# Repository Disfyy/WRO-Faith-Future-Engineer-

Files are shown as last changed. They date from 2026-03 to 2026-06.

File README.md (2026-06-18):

# WRO Future Engineers 2026 - Team Faith 🚀





Official repository for **Team Faith**, participating in the World Robot Olympiad (WRO) Future Engineers category. This repository contains all source code (Vision and Control), electromechanical schemes, and project documentation for our autonomous vehicle.

---

## 👋 For first-time viewers / WRO judges

If you've just landed on this repo, start here:

| What you want | Where to look |
|---|---|
| **What this robot does** | [Hardware](#-main-hardware-components-v13) and [Software Architecture](#-software-architecture) below |
| **Active firmware (the file we actually flash)** | [`src/esp32/wro_v13_main.cpp`](src/esp32/wro_v13_main.cpp) — build target 11 |
| **How we test the robot** | [Testing & Calibration Workflow](#-testing--calibration-workflow) below |
| **Source code map** | [`src/esp32/README.md`](src/esp32/README.md) (control firmware) · [`src/openmv/README.md`](src/openmv/README.md) (original vision backend) · [`src/espcam/README.md`](src/espcam/README.md) (active Pixy2 vision backend) |
| **Engineering journal** | [`docs/`](docs/) — checklists, guides, strategy, run logs, rules |
| **Engineering writeups (WRO rubric)** | [`other/`](other/) — mobility / power-and-sense / obstacle management |
| **3D-printable parts** | [`models/HSP94182_3D/`](models/HSP94182_3D/) |
| **Wiring & system diagrams** | [`schemes/`](schemes/) |
| **Photos & video** | [`v-photos/`](v-photos/), [`t-photos/`](t-photos/), [`video/`](video/) |

> 📝 The robot is in **bench calibration** as of this writing — race-day logs in [`docs/logs/`](docs/logs/) are still template-only. See [`CHANGELOG.md`](CHANGELOG.md) for status.

---

## 🏎️ Main Hardware Components (v13)
Our vehicle is built on a custom-designed reliable chassis equipped with a powerful processing stack to ensure optimal performance in both Open Challenge and Obstacle Challenge.

- **Main Controller:** ESP32-S3-DevKitC-1 N8R8 (PID, Odometry, FSM)
- **Computer Vision:** Pixy2/2.1 (active backend — color blob tracking + obstacle distance). OpenMV H7 Plus is the original/fallback backend; its OV5640 sensor failed 5 days before competition, see `wro_config_v13.h` §12.
- **IMU:** Adafruit ICM-20948 (9-DoF, on I2C0)
- **Encoders:** 2× AS5600 magnetic encoders (12-bit, dual I2C — one per bus, no mux)
- **Distance:** 2× VL53L1X ToF sensors (XSHUT-based runtime address remap)
- **Motor Driver:** BTS7960 (43A H-Bridge)
- **Steering:** JX PDI-6221MG digital servo
- **Power:** 2S/3S LiPo + 5V step-down

> **No I2C multiplexer.** The original v11 build used a TCA9548A to share one I2C bus across two AS5600s and two VL53L1Xs; that mux burned out. v13 instead uses both native I2C peripherals on the ESP32-S3 (one AS5600 per bus) and runtime XSHUT-based address remapping for the VL53L1X pair.

## 🧠 Software Architecture

Our software is divided into two continuous independent threads:
1. **Vision System (`src/openmv/`):** A MicroPython script running on the OpenMV camera. It scans for 4 target colors (Orange/Blue for directions, Red/Green for obstacles) and black walls. It calculates dynamic tracking errors and distances, transmitting payloads via UART at `115200` baud.
2. **Control System (`src/esp32/`):** A layered architecture (HAL → estimation → behavior → control → top FSM) running on the ESP32-S3. Active firmware: `wro_v13_main.cpp` (build target 11).

### Algorithms Implemented
*   **Finite State Machine (FSM):** `INIT → WAIT_START → RUN_OPEN | RUN_OBS → (corner FSM, parking FSM) → FINISH`, with `SAFE_STOP` available from any running state.
*   **Cornering FSM:** Owned by front-distance + IMU yaw delta — the camera is never an exit condition. Encoder ticks are telemetry-only during the turn.
*   **Dynamic Offset PID:** Setpoint shifts ±60 px when an active pillar is in view; far pillar provides a 0.4× pre-position term when both colors are visible.
*   **Hardware E-Stop:** Press+release arms the start; held during the race triggers `SAFE_STOP` and resumes on release.
*   **Finish Zone Odometry:** Dual AS5600 encoders track post-3-laps distance to land the robot in the finish band.
*   **Pixy2 Camera Backend:** Binary block-protocol driver (`wro_camera_pixy2.cpp`) feeding the same `g_cam` struct as the OpenMV backend, so FSM/failsafes/telemetry stay backend-agnostic. See [`docs/guides/WRO_Pixy2_Setup.md`](docs/guides/WRO_Pixy2_Setup.md).
*   **Steering Asymmetry Trim:** Live-tunable per-side steering gain compensation (`wro_steering_comp.h`) to correct chassis bias.
*   **Encoder Health Diagnostics:** Magnet-presence and connection-stability checks (target 8) run before odometry is trusted.
*   **Wi-Fi Telemetry Mirror (testing only):** Optional softAP + UDP broadcast of telemetry for bench debugging (`wro_telemetry_wifi.cpp`), gated off by default — disabled for competition per Rule 11.10.

---

## 📂 Repository Structure

```text
├── models/HSP94182_3D     # 3D chassis CAD (STL / STEP / SCAD / Python + viewer.html)
├── schemes                # Electromechanical diagrams (Mermaid + rendered PNG/SVG)
├── src
│   ├── esp32              # ESP32-S3 control firmware (C++) — v13 modular layers
│   │   ├── wro_v13_main.cpp        # Production firmware (target 11) ← active
│   │   ├── diag_*.cpp              # Diagnostic targets (2, 8, 9, 10, 12)
│   │   ├── wro_*.{cpp,h}           # Layered HAL / estimation / behavior / FSM
│   │   ├── as5600_dual_i2c.h       # AS5600 driver (dual I2C, no mux)
│   │   ├── vl53l1x_dual.h          # VL53L1X driver (XSHUT addr remap)
│   │   ├── wro_build_target.h      # Edit one line to switch target
│   │   └── legacy/                 # v11 archived sources (legacy_*.cpp + README)
│   ├── openmv              # MicroPython machine-vision scripts (original/fallback backend)
│   └── espcam              # ESP32-CAM + Pixy2 vision sketch (active backend, see espcam/README.md)
├── sketches               # Standalone Arduino sketches (bench tests, servo cal)
├── other                  # Engineering writeups by WRO topic
│   ├── mobility-management              # Drivetrain, steering, chassis, control loops
│   ├── power-and-sense-management       # Battery, power dist., sensor stack
│   └── obstacle-management              # Obstacle Challenge strategy + parking
├── docs                   # Project documentation
│   ├── INDEX.md           # Single-page navigation hub
│   ├── guides             # Wiring map, assembly, servo cal, UART protocol
│   ├── checklists         # Race-day preflight & log
│   ├── strategy           # Migration, rule compliance, audit, risk, templates
│   ├── logs               # PID / maintenance / test CSV logs
│   └── rules              # Official WRO 2026 rules (reference copies)
├── t-photos               # Team presentation photos
├── v-photos               # Vehicle engineering photos
├── video                  # Demonstration recordings
├── CHANGELOG.md           # Versioned engineering history
└── README.md              # You are here
```

## ⚙️ How to Setup

1. Assemble and wire the chassis according to [`docs/guides/WRO_Wiring_Map_v13.md`](docs/guides/WRO_Wiring_Map_v13.md).
2. Camera (active backend, Pixy2): teach signatures in PixyMon per [`docs/guides/WRO_Pixy2_Setup.md`](docs/guides/WRO_Pixy2_Setup.md) and set "Data out port" to UART @ 115200 baud. *(Fallback backend, OpenMV: connect to the IDE, run Threshold Editor to configure field lighting, and save `openmv_main.py` directly to the camera flash as `main.py`.)*
3. In Arduino IDE, install `Adafruit ICM20948`, `ESP32Servo`, and `VL53L1X` (by Pololu). Open the `src/esp32/` folder as a sketch, set `WRO_ACTIVE_TARGET` in `wro_build_target.h` to `WRO_TARGET_V13_MAIN` (target 11) and flash. Entry point is `src/esp32/wro_v13_main.cpp`.
4. Select challenge mode at compile time: `OBSTACLE_MODE 0` (Open) or `1` (Obstacle) in `src/esp32/wro_config_v13.h` (Rule 9.9: no physical mode switches). Place on the track, press the E-Stop button to start.

> ℹ️ The hardware was on a v12 plan (ESP32-S3 + AS5048A SPI + TFMini-S UART) but the new sensors didn't arrive in time and the v11 TCA9548A mux burned out. **v13 is the actual fielded build:** new ESP32-S3 main controller + original v11 sensors (AS5600 + VL53L1X), with the address conflicts resolved via dual native I2C peripherals and runtime XSHUT-based VL53L1X address remapping. See [`CHANGELOG.md`](CHANGELOG.md) and [`docs/strategy/WRO_Migration_v12_to_v13.md`](docs/strategy/WRO_Migration_v12_to_v13.md) for the full story.

---

## 🧪 Testing & Calibration Workflow

We test the robot in **two layers** before any race-pace driving:

### Layer 1 — Subsystem diagnostics

Standalone programs that verify one piece of hardware at a time. Run these in order before every test session:

| Order | What we test | How to run |
|---:|---|---|
| 1 | Both I2C buses + every address | Set target 2 ([`src/esp32/diag_scan_i2c_v13.cpp`](src/esp32/diag_scan_i2c_v13.cpp)) |
| 2 | Both AS5600 encoders: connection, magnet health, stability, odometry (keys `s`/`m`/`z`/`h`) | Set target 8 ([`src/esp32/diag_test_encoders.cpp`](src/esp32/diag_test_encoders.cpp)) |
| 3 | Both VL53L1X ToF after XSHUT remap | Set target 9 ([`src/esp32/diag_test_vl53l1x.cpp`](src/esp32/diag_test_vl53l1x.cpp)) |
| 4 | Full bench (IMU + servo + motor + camera + E-Stop) | Set target 10 ([`src/esp32/diag_bench_test_v13.cpp`](src/esp32/diag_bench_test_v13.cpp)) |
| 5 | Camera link check (active backend per `CAMERA_BACKEND`) | Set target 12 ([`src/esp32/diag_test_camera.cpp`](src/esp32/diag_test_camera.cpp)) |

Switch targets by editing one line in [`src/esp32/wro_build_target.h`](src/esp32/wro_build_target.h). Standalone `.ino` versions for the Arduino IDE live in [`sketches/`](sketches/).

### Layer 2 — Production firmware

When all 5 diagnostics pass, switch to target 11 ([`src/esp32/wro_v13_main.cpp`](src/esp32/wro_v13_main.cpp)) — the actual race firmware. It logs CSV-formatted telemetry over USB serial at 5 Hz.

### Logging

Every test-drive session is logged into [`docs/logs/`](docs/logs/):

- `WRO_Test_Log.csv` — preflight + run results (one row per session)
- `WRO_PID_Tuning_Log.csv` — controller gain experiments
- `WRO_Maintenance_Log.csv` — hardware changes

> Logs are currently **template-only** because the v13 chassis is still in bench calibration. They'll be populated as we move into floor and track testing.

### Checklists & guides

- Race-day quick check: [`docs/checklists/WRO_Quick_Race_Checklist.md`](docs/checklists/WRO_Quick_Race_Checklist.md)
- Full preflight log template: [`docs/checklists/WRO_Preflight_Log.md`](docs/checklists/WRO_Preflight_Log.md)
- Master checklist (every subsystem): [`docs/checklists/WRO_Robot_Master_Checklist_2026-03-27.md`](docs/checklists/WRO_Robot_Master_Checklist_2026-03-27.md)
- Step-by-step migration verification: [`docs/strategy/WRO_Migration_v12_to_v13.md`](docs/strategy/WRO_Migration_v12_to_v13.md)

---

## 📚 Reading Order (for judges and new readers)

1. **This README** — you are here.
2. **Engineering writeups by topic** — three short docs, one per WRO rubric area:
   - [`other/mobility-management/`](other/mobility-management/) — drivetrain, steering, chassis, control loops
   - [`other/power-and-sense-management/`](other/power-and-sense-management/) — battery, power, sensors
   - [`other/obstacle-management/`](other/obstacle-management/) — Obstacle Challenge strategy + parking
3. **Reference docs** — the [`docs/INDEX.md`](docs/INDEX.md) lists every document grouped by use-case (guides, checklists, strategy, logs, rules).
4. **Source** — vision in [`src/openmv/`](src/openmv/), control in [`src/esp32/`](src/esp32/) (entry point [`wro_v13_main.cpp`](src/esp32/wro_v13_main.cpp), tunables in [`wro_config_v13.h`](src/esp32/wro_config_v13.h)).
5. **Engineering history** — [`CHANGELOG.md`](CHANGELOG.md) tells the v11 → v12-plan → v13-actual story chronologically.

---

> *"Engineering is the closest thing to magic that exists in the world."* 
> 
> **— Team Faith**

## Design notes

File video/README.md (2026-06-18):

# `video/` — Demonstration video

Pending. The WRO Future Engineers category requires a video showing the
robot completing each challenge:

- **Open Challenge** — three full laps on the track with randomized
  inner/outer wall sections.
- **Obstacle Challenge** — three laps with red/green traffic-sign
  pillars + the magenta parking-lot finishing maneuver.

## How this will be linked

Submitted videos are typically hosted on **YouTube** (unlisted or public)
and linked from this README rather than checked into the repo — `.mp4`
files are too large for normal Git workflows.

When the first clean run is captured (per the calibration protocol, this
follows Stage 4 — first reliable 3-lap Open Challenge runs), this file
will be updated with:

- YouTube URL https://youtu.be/xa8ygO6oQPE?si=rebM9Lfaib3Sgx73
- Run date and conditions (lighting, battery voltage, firmware commit)
- Brief description of what's shown

Until then, this folder intentionally contains only a `.gitkeep`.

https://youtu.be/xa8ygO6oQPE?si=rebM9Lfaib3Sgx73

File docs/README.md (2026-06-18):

# `docs/` — WRO Future Engineers documentation

All written documentation for Team Faith's WRO robot lives here, grouped by
purpose so a judge (or a teammate) can find what they need fast.

> Looking for everything in one place? Open [`INDEX.md`](INDEX.md) for the
> full table-of-contents.

## Subfolders

| Folder | What's inside |
|---|---|
| [`guides/`](guides/) | Engineering reference: wiring map, assembly + startup, servo calibration, OpenMV UART protocol, Pixy2 setup |
| [`checklists/`](checklists/) | Race-day operations: master preflight, quick-race checklist, fillable preflight log |
| [`strategy/`](strategy/) | Analysis & planning: migration history, rule-compliance matrix, characteristics audit, track test cases, risk register, templates |
| [`logs/`](logs/) | Running CSV logs: PID tuning, maintenance, test results |
| [`rules/`](rules/) | Official WRO 2026 Future Engineers rules (reference copies, MD + PDF) |

## At a glance

### Firmware (`src/esp32/`) — for context, not maintained here

The active build is **v13** (ESP32-S3, dual native I2C, no mux). Entry point
`wro_v13_main.cpp` (target 11). v11 sources are archived under
[`../src/esp32/legacy/`](../src/esp32/legacy/).

### Recommended preflight workflow (v13)

1. `diag_scan_i2c_v13.cpp` (target 2) — verify both buses, expected addresses on each.
2. `diag_test_encoders.cpp` (target 8) — verify both AS5600s on dual-I2C: connection, magnet health, stability, then accumulate ticks.
3. `diag_test_vl53l1x.cpp` (target 9) — verify front + side VL53L1X come up post-XSHUT-remap.
4. `diag_bench_test_v13.cpp` (target 10) — full hardware sanity check.
5. `diag_test_camera.cpp` (target 12) — verify the active camera backend (Pixy2 by default, see `CAMERA_BACKEND` in `wro_config_v13.h`) responds over UART.
6. `wro_v13_main.cpp` (target 11) — wheels-up smoke test.
7. On-track tuning — straight, single corner, full lap.

For step-by-step preflight see
[`checklists/WRO_Robot_Master_Checklist_2026-03-27.md`](checklists/WRO_Robot_Master_Checklist_2026-03-27.md)
and [`checklists/WRO_Quick_Race_Checklist.md`](checklists/WRO_Quick_Race_Checklist.md).

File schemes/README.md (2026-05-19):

# Schemes

Wiring diagrams and system schematics for the WRO Future Engineers vehicle.
All files in this folder describe the **v13 hardware** (ESP32-S3 + 2× AS5600
on dual native I2C + 2× VL53L1X with XSHUT-based runtime address remap, no
TCA9548A mux).

## Files

| File | Format | Notes |
|---|---|---|
| `WRO_Wiring_Map.md` | Markdown | Summary pin table; full reference at [`../docs/guides/WRO_Wiring_Map_v13.md`](../docs/guides/WRO_Wiring_Map_v13.md) |
| `WRO_Full_System_Diagram.md` | Markdown + embedded Mermaid | System block diagram with prose |
| `WRO_Full_System_Diagram.mmd` | Mermaid source | Same diagram, source only |
| `WRO_Full_System_Diagram.svg` / `.png` | Rendered | Generated from the `.mmd` above |
| `WRO_Detailed_Wiring_Diagram.mmd` | Mermaid source | Pin-by-pin connectivity view |
| `WRO_Detailed_Wiring_Diagram.svg` / `.png` | Rendered | Generated from the `.mmd` above |

## Regenerating the rendered diagrams

If you edit a `.mmd` source, re-render with one of:

- **Mermaid CLI (mmdc):**
  ```
  npx -y @mermaid-js/mermaid-cli -i WRO_Full_System_Diagram.mmd -o WRO_Full_System_Diagram.svg
  npx -y @mermaid-js/mermaid-cli -i WRO_Full_System_Diagram.mmd -o WRO_Full_System_Diagram.png -w 2400
  npx -y @mermaid-js/mermaid-cli -i WRO_Detailed_Wiring_Diagram.mmd -o WRO_Detailed_Wiring_Diagram.svg
  npx -y @mermaid-js/mermaid-cli -i WRO_Detailed_Wiring_Diagram.mmd -o WRO_Detailed_Wiring_Diagram.png -w 2400
  ```
- **Mermaid Live Editor:** paste the `.mmd` content into [mermaid.live](https://mermaid.live/) and export.

## Authoritative pin reference

The full v13 pin map with notes lives at [`../docs/guides/WRO_Wiring_Map_v13.md`](../docs/guides/WRO_Wiring_Map_v13.md). The `.md` files in this folder summarize that reference visually.

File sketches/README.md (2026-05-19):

# `sketches/` — Standalone Arduino sketches

These are self-contained Arduino IDE sketches (one `.ino` per folder) for
**bench bring-up** and **subsystem testing**. Each one flashes to the
ESP32-S3 without the rest of the v13 codebase — useful when you want to
verify a single subsystem in isolation, or hand a tester to someone who
only has the Arduino IDE.

## How this differs from `src/esp32/`

The production firmware lives in [`../src/esp32/`](../src/esp32/) and uses a
**build-target macro system** (one sketch, switch which target compiles
via `WRO_ACTIVE_TARGET`). That's the right path for race firmware and
preflight diagnostics, but it requires opening the multi-file sketch.

The sketches in this folder are the **standalone alternative**: each is
one `.ino` with everything inlined. Open it, flash it, watch Serial.

## Sketches

| Folder | Sketch | Purpose |
|---|---|---|
| [`bench_test/`](bench_test/) | `bench_test.ino` | Full robot bench check — IMU, both AS5600, both VL53L1X (with XSHUT remap), steering servo, BTS7960 motor, E-Stop, OpenMV UART. Serial commands: `s` status, `live` toggle, `sl/sc/sr` servo, `f/b/fast/stop` motor. **Lift wheels before flashing.** |
| [`servo_calibrate/`](servo_calibrate/) | `servo_calibrate.ino` | Sweep the JX PDI-6221MG digital servo over a microsecond range to find left/center/right values. Use this to determine the `SERVO_*_US` constants in [`../src/esp32/wro_config_v13.h`](../src/esp32/wro_config_v13.h). Procedure: [`../docs/guides/WRO_Servo_Calibration_Guide.md`](../docs/guides/WRO_Servo_Calibration_Guide.md). |
| [`test_encoders/`](test_encoders/) | `test_encoders.ino` | Print live tick counts from both AS5600 encoders on dual I2C. Spin a wheel by hand; values should change smoothly. 1 revolution ≈ 4096 ticks; 1 cm ≈ 277 ticks (47 mm wheel). |

## Required libraries

Same as the main firmware:
- `Adafruit ICM20948` (+ `Adafruit BusIO` + `Adafruit Unified Sensor`)
- `ESP32Servo`
- `VL53L1X` by **Pololu**

Board: **ESP32-S3 Dev Module**. Serial Monitor: **115200 baud**.

## When to use a sketch vs. a `src/esp32/diag_*.cpp` target

| Situation | Use |
|---|---|
| Race-day preflight, you already have the main sketch open | `src/esp32/diag_*.cpp` (set `WRO_ACTIVE_TARGET`) |
| Handing a hardware test to a teammate with only Arduino IDE | This folder |
| Calibrating servo center values | `sketches/servo_calibrate/` (the diag flow doesn't have an equivalent — yet) |
| First-time bring-up after re-soldering | Either; pick the one you already have flashed |

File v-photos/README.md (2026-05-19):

# `v-photos/` — Vehicle photos

Engineering photos of the assembled Team Faith WRO v13 robot, one per
canonical view. WRO Future Engineers documentation requires photos of the
vehicle from every side so judges can evaluate mechanical design without
seeing the robot in person.

## Photos

| File | View | What's visible |
|---|---|---|
| [`top.jpeg`](top.jpeg) | Top-down | ESP32-S3-DevKitC-1, OpenMV H7 Plus camera mount, IMU, wiring harness |
| [`bottom.jpeg`](bottom.jpeg) | Bottom | Drivetrain layout, motor + gearbox, both AS5600 encoder magnets, chassis frame |
| [`front side.jpeg`](front%20side.jpeg) | Front | Steering linkage, front VL53L1X ToF, camera field-of-view direction |
| [`left side.jpeg`](left%20side.jpeg) | Left | Side VL53L1X ToF, battery placement, cable routing |
| [`right side.jpeg`](right%20side.jpeg) | Right | Motor driver (BTS7960), power distribution, E-Stop button access |

> 📝 **Captions are provisional** — they reflect what should be visible in
> each view based on the v13 build. Update this table before submission if
> any photo shows something different, and re-take any photo where the
> labeled component isn't actually visible.

## Photo requirements (per WRO Future Engineers documentation rules)

- At least one photo from each of the 6 standard views (top, bottom,
  front, back, left, right). Currently missing: **back view**.
- Photos should be sharp, well-lit, and taken against a plain background.
- The robot should be in its competition configuration (no debug wires,
  no removed panels) when photographed for the final submission.

## See also

- 3D CAD reference: [`../models/HSP94182_3D/`](../models/HSP94182_3D/) — the
  same robot from any angle, in 3D.
- Wiring diagrams: [`../schemes/`](../schemes/) — abstracted views of the
  electronics shown in these photos.

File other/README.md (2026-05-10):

# `other/` — Engineering documentation by WRO topic

The WRO Future Engineers rubric scores three engineering areas separately.
This folder organises Team Faith's design rationale by those three areas
so a judge can read each concern in isolation. Each subfolder contains a
self-contained writeup that links out to the canonical sources of truth
(source code, schematics, detailed guides) elsewhere in the repo.

| Area | Folder |
|---|---|
| Drivetrain, steering, chassis, speed control | [`mobility-management/`](mobility-management/) |
| Battery, power distribution, sensor selection & integration | [`power-and-sense-management/`](power-and-sense-management/) |
| Obstacle Challenge strategy, pillar handling, parking | [`obstacle-management/`](obstacle-management/) |

> Authoritative documentation continues to live in `docs/` and `src/`.
> Files here are explanatory writeups *about* those sources, not copies of them.

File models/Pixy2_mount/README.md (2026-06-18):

# Pixy2 / Pixy2.1 Camera Mount — WRO FE 2026 · Team Faith

Drop-in replacement for the OpenMV H7 mount after the OpenMV sensor module was
damaged (2026-06-12). Holds a **Pixy2 / Pixy2.1** board at the front of the
electronics box, aimed forward and tilted **15° down** so the lens sees the
track + pillars ahead. Reuses the **same base footprint** and matches the
**OpenMV lens height** so `PIXY_FOCAL_PIX` in `wro_config_v13.h` barely shifts.

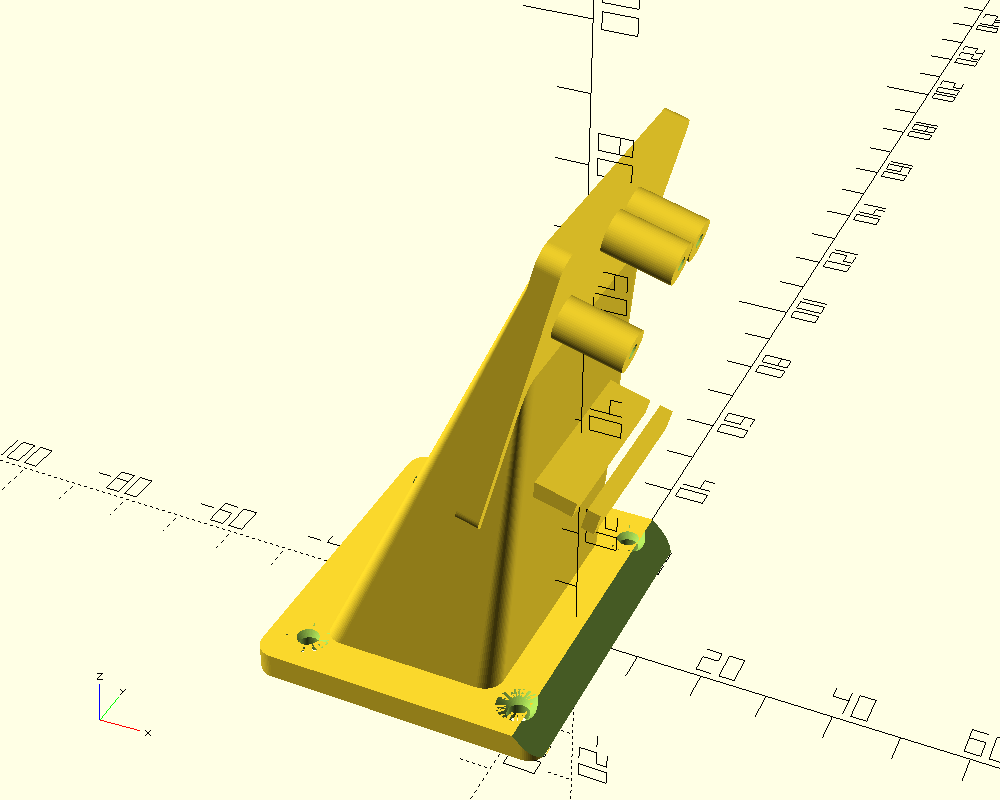
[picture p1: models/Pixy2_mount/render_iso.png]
iso

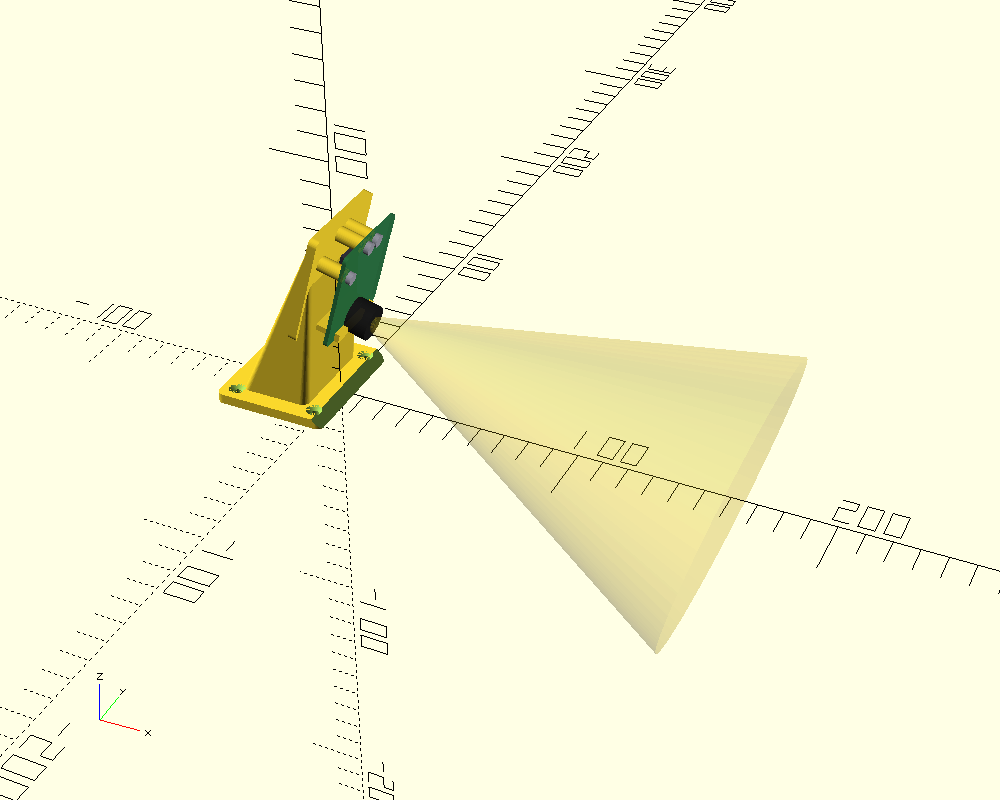
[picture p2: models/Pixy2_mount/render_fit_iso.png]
fit check

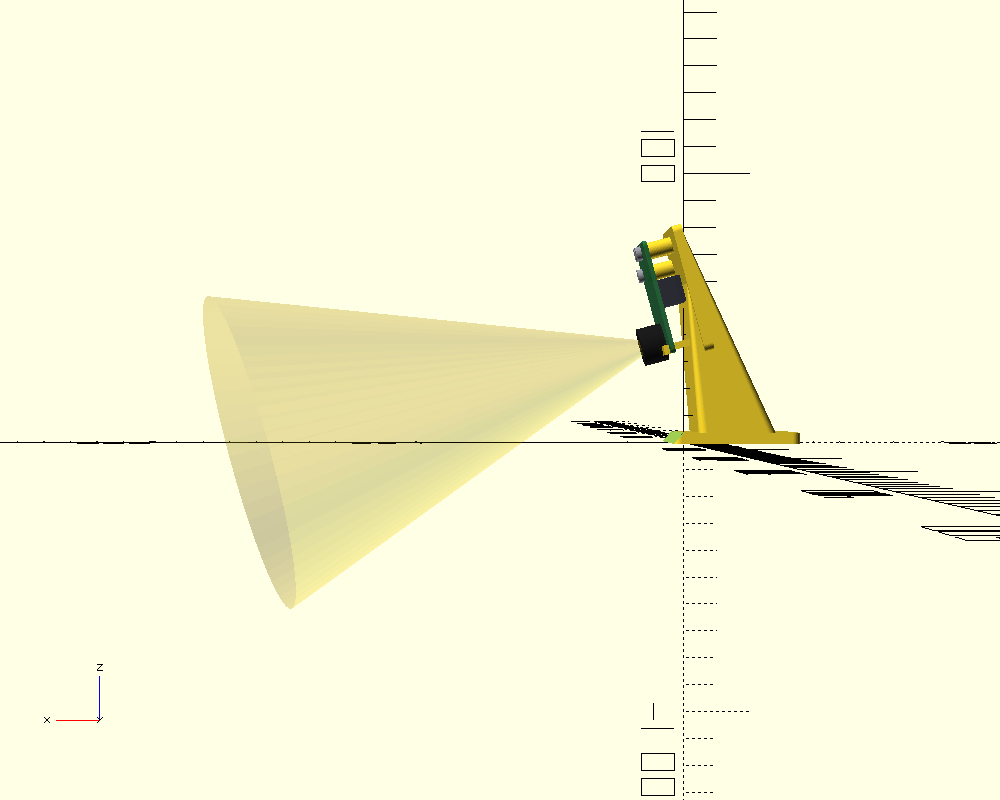
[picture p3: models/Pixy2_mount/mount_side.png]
side / aim


## Capture style — bolt-through

The board bolts onto **3 printed standoff bosses** using Pixy2's own three
mounting holes. Screws enter from the **front** (lens side); all 3 holes sit
high on the board and the lens sits low, so the heads never touch the optical
path. The 10-pin ribbon hangs in the air gap behind the board and exits a slot
in the bottom edge of the backplate. A bottom lip carries the board's weight.

## ⚠️ Correction to WRO_Pixy2_Setup.md

That guide says "M2.5, 4 holes at the corners." The
[official dimensions](https://docs.pixycam.com/wiki/doku.php?id=wiki:v2:dimensions)
say otherwise — this mount follows the official numbers:

| Spec | Official value |
|---|---|
| PCB | **38.25 × 42 mm** |
| Mounting holes | **3 holes, ⌀3.0 mm** (not 4) |
| Hole coords (corner origin) | (5.1, 31.3) · (16.0, 38.8) · (22.4, 38.8) |
| Lens centre | (19.0, 5.0) — low/centred |
| Fasteners | Pixy ships **4-40**; **M2.5** also passes the 3 mm holes |

## Hardware

- **3 × M2.5 self-tapping screws** (~6–8 mm) — board → bosses. Default pilot
  `PILOT_D = 2.1` self-taps into PLA/PETG. *(4-40 self-tappers also work.)*
- **Optional upgrade:** set `HEATSET = true` to widen the pilot for M2.5
  heat-set inserts (more re-mate cycles, better for a vibrating robot).
- **4 × M3 screws** — base → chassis (countersunk from the top, same as the
  OpenMV mount's footprint).

## Print settings

PLA or PETG · 0.2 mm layer · ≥ 30 % infill (vibration) · **supports ON** under
the backplate overhang and the bosses · brim recommended (tall, narrow part).
Print orientation: base flat on the bed (as modelled).

## Assembly

1. Bolt the base to the chassis at the **same 4 holes** the OpenMV mount used.
2. Drop the Pixy onto the 3 bosses, ribbon facing down into the rear gap.
3. Drive 3 × M2.5 from the front through the board into the bosses — snug, not
   crushing the PCB.
4. Route the ribbon down through the bottom slot to the ESP32-S3 (GPIO17/18, 5 V, GND).

## Tuning parameters (`pixy2_mount.scad`)

| Param | Default | Note |
|---|---|---|
| `TILT_DEG` | 15 | lens downtilt — keep equal to the OpenMV mount |
| `LENS_TARGET_Z` | 40 | **MEASURE your built OpenMV mount's lens height and match it** |
| `STANDOFF` | 10 | board↔backplate gap; must clear the 10-pin connector |
| `PILOT_D` / `HEATSET` | 2.1 / false | M2.5 self-tap vs heat-set insert |
| `CONN_WINDOW` | false | cut a window for the connector if you shorten `STANDOFF` |
| `CABLE_W` | 14 | ribbon slot width |

## ⚠️ Verify with calipers before printing

Same rule as the AS5600 bracket and the OpenMV mount:
- `PCB_T` (PCB thickness, ~1.6)
- the **connector block** height/footprint → confirm `STANDOFF ≥` its protrusion
- your **built OpenMV mount's lens height** → set `LENS_TARGET_Z` to match

## Note: taller than the OpenMV mount

Because Pixy's lens sits near the **bottom** of a tall board, matching the
OpenMV lens height (~40 mm) puts the board top around **77 mm**. Held by 3 top
bolts + the bottom lip it's rigid, but the centre of mass is higher than the
OpenMV mount — keep the base screws tight and re-check after a few runs.

## Export

```bash
# from this folder
openscad -o pixy2_mount.stl pixy2_mount.scad
# fit-check renders (board + lens cone + connector ghosts):
openscad -o render_fit_iso.png -D 'SHOW_GHOSTS=true' --viewall --autocenter pixy2_mount.scad
```

Set `SHOW_GHOSTS = false` (default) before exporting the printable STL.

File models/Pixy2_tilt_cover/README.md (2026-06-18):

# Pixy2 / Pixy2.1 Tilt-Adjustable Cover — WRO FE 2026 · Team Faith

A box **cover** that encloses the Pixy2 and hangs on a **clevis hinge**, so the
camera downtilt is **adjustable** (loosen one M3, swing, re-tighten) instead of
the fixed 15° of [`models/Pixy2_mount`](../Pixy2_mount/). Modelled after the
GrabCAD "Pixy Camera Case" pivot concept, fitted to Pixy2's official geometry.

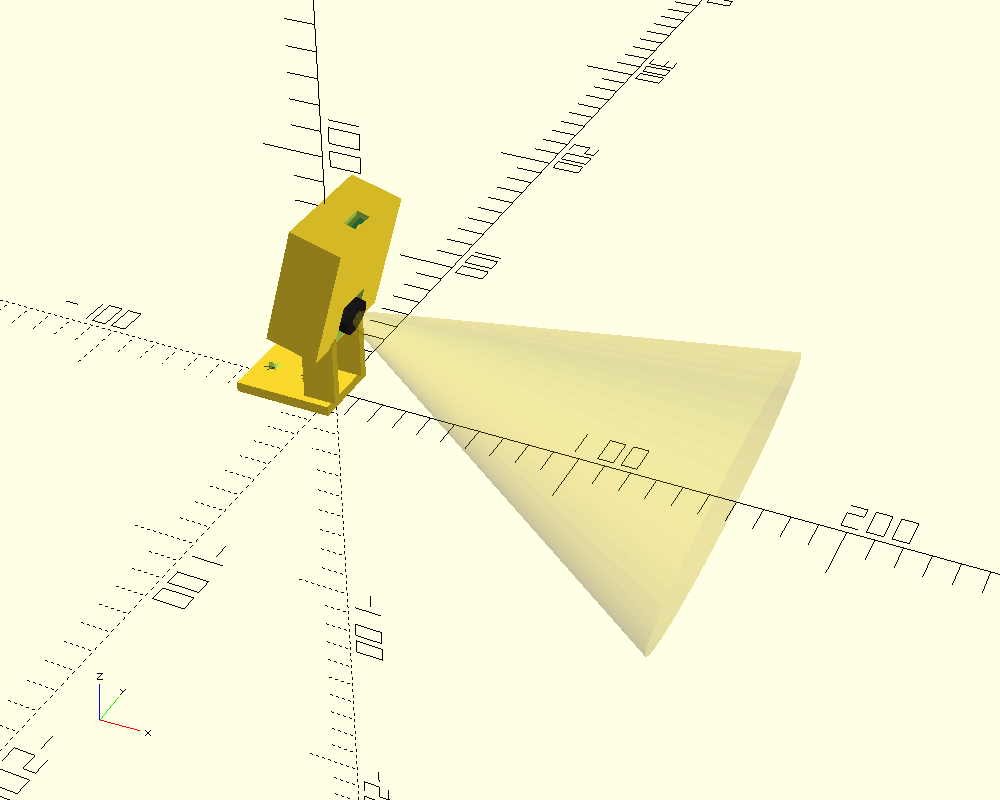
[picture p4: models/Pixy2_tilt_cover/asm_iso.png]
assembly

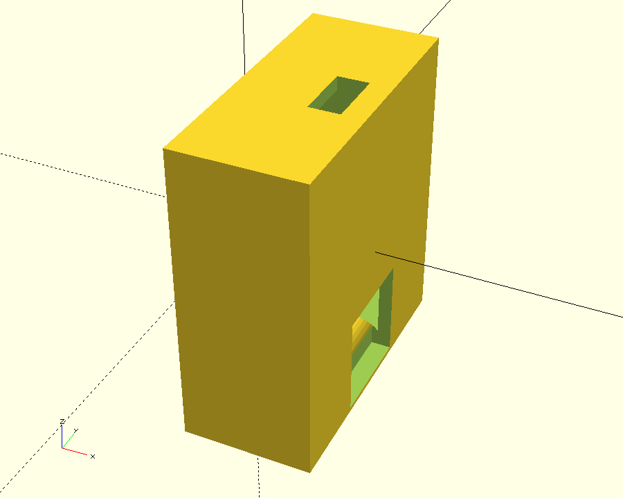
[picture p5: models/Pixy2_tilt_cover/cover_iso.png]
cover

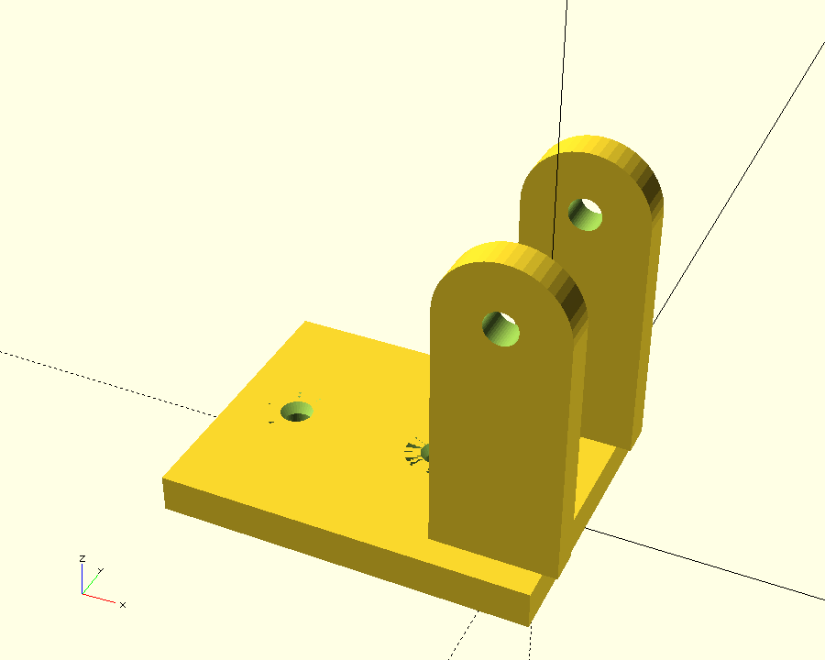
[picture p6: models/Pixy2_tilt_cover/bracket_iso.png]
bracket


## Two printed parts

| Part | File | What it is |
|---|---|---|
| **Cover** | `cover.stl` | camera box: lens window, top button slot, open back, hinge barrel |
| **Bracket** | `bracket.stl` | L-foot (chassis screws) + clevis ears that straddle the barrel |

Render each from the one source:
```bash
openscad -o cover.stl   -D 'SHOW="cover"'   pixy2_tilt_cover.scad
openscad -o bracket.stl -D 'SHOW="bracket"' pixy2_tilt_cover.scad
# assembly fit-check (board + lens cone ghost):
openscad -o asm_iso.png -D 'SHOW="assembly"' -D 'SHOW_GHOSTS=true' --viewall --autocenter pixy2_tilt_cover.scad
```

## How the tilt works

The cover's hinge **barrel** (bottom-front) sits between the bracket's two
**clevis ears**, pinned by **one M3 screw**. Loosen → the cover swings about the
horizontal pivot axis → set the downtilt → tighten to **friction-lock**.

> ⚠️ **Locking:** a single M3 on a cantilevered box can creep under vibration.
> Use an **M3 nyloc** (not a plain nut) and tighten firmly; add a **serrated /
> star washer** under the head for grip. The wide `BARREL_R = 5` gives a large
> friction radius on purpose. If it still slips, raise `BARREL_R`, or add radial
> teeth to the barrel ends + ears (future upgrade).

## Hardware

- **1 × M3 × 20 + M3 nyloc** — the pivot pin.
- **3 × M2.5 self-tapping** (~6 mm) — board → the 3 internal bosses (Pixy2's
  own 3 × ⌀3 mm holes). Insert from the **open back**.
- **2 × M3** — bracket foot → chassis (countersunk from the top).

## Assembly

1. Drop the Pixy into the cover from the **open back**, lens into the front
   window, board onto the 3 bosses; drive 3 × M2.5 from the back.
2. Route the 10-pin ribbon out the open back / bottom relief.
3. Put the barrel between the bracket ears, push the M3 through, add the nyloc
   **loosely**.
4. Bolt the bracket foot to the chassis (2 × M3).
5. Power up, watch the Pixy view, swing to the downtilt you want, **tighten the
   M3**. Re-calibrate `PIXY_FOCAL_PIX` (§4 of WRO_Pixy2_Setup.md) at the chosen
   angle.

## Print settings

PLA/PETG · 0.2 mm · ≥ 30 % infill · supports ON.
- **Cover:** print open-back-down (back opening on the bed) → walls print as
  vertical perimeters; the hinge barrel needs a little support.
- **Bracket:** print foot-down; the clevis ears need support under the rounded
  tops.

## Key parameters (`pixy2_tilt_cover.scad`)

| Param | Default | Note |
|---|---|---|
| `TILT_DEG` | 15 | **demo angle for the render only** — real tilt is set by the hinge |
| `PIVOT_Z` / `PIVOT_X` | 30 / 0 | pivot-axis height / fwd-back vs chassis |
| `BARREL_R` / `BARREL_L` | 5 / 16 | hinge barrel size (friction radius / width) |
| `PIN_D` | 3.4 | M3 pivot clearance |
| `CONN_DEPTH` / `LENS_BARREL` | 11 / 9 | **MEASURE** connector + lens protrusion |
| `PCB_T` | 1.6 | **MEASURE** |
| `WIN_HALF` | 8 | lens window half-size (clears the 14 mm barrel) |

## ⚠️ Verify with calipers before printing

- `PCB_T`, the **lens-barrel length** (`LENS_BARREL`), and the **connector
  depth** (`CONN_DEPTH`) — these set the box depth and whether the lens reaches
  the window / the connector clears the interior.
- Pixy2 board + holes follow
  [official dims](https://docs.pixycam.com/wiki/doku.php?id=wiki:v2:dimensions):
  38.25 × 42 mm, 3 × ⌀3 mm holes at (5.1,31.3)(16,38.8)(22.4,38.8), lens (19,5).

## vs. the fixed mount

| | `Pixy2_mount` (fixed) | `Pixy2_tilt_cover` (this) |
|---|---|---|
| Tilt | fixed 15° (re-print to change) | **adjustable, locked by M3** |
| Protection | open cradle | **enclosed box cover** |
| Parts / hardware | 1 part, 3×M2.5 + 4×M3 | 2 parts, +1×M3 nyloc pivot |
| Risk | none moving | pivot can creep if under-tightened |

Use the fixed mount once the best angle is known; use this to **find** that
angle on the track, or if you want the lens protected.

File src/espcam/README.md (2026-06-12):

# ESP32-CAM аварийное зрение (план Б вместо OpenMV)

**Зачем:** сенсор-модуль OpenMV H7 Plus повреждён (2026-06-12), до соревнования 5 дней.
Эта прошивка превращает ESP32-CAM в «поддельный OpenMV»: она шлёт **тот же UART-кадр
v3.1** (`RedX,RedDist,GreenX,GreenDist,ModeFlag,ExtraTag*XX\n`, 115200 8N1), поэтому
**прошивка робота (wro_v13_main.cpp) не меняется вообще**.

Файл: `espcam_vision/espcam_vision.ino`

---

## 1. Прошивка платы

Нужен USB-TTL адаптер (CH340/FTDI/CP2102) или подставка ESP32-CAM-MB.

| USB-TTL | ESP32-CAM |
|---|---|
| TX | U0R |
| RX | U0T |
| GND | GND |
| 5V | 5V |

1. Замкни **IO0 → GND** проводом.
2. Подключи USB — плата в режиме загрузки.
3. Arduino IDE: плата **"AI Thinker ESP32-CAM"** (Tools → Board → esp32).
4. Открой `espcam_vision.ino` → Upload.
5. После «Done uploading» сними перемычку IO0, нажми RST.
6. В Serial Monitor (115200) должно появиться `[CAM] OV2640 up` и `[NET] tuner at http://192.168.4.1`.

**Если плата не AI-Thinker** (нет надписи) — сфотографировать и спросить Claude,
распиновка камеры может отличаться.

## 2. Подключение к роботу

| ESP32-CAM | Куда |
|---|---|
| GPIO13 (TX) | ESP32-S3 **GPIO17** (UART2 RX — туда, где был TX OpenMV) |
| GND | GND робота |
| 5V | 5V с бака (≥500 мА). **НЕ** с пина 3V3 |

- **GPIO12 не подключать никуда** (страповый пин — плата не загрузится).
- Линия односторонняя: камера только передаёт, как и OpenMV.

## 3. Настройка порогов (вместо OpenMV IDE)

1. Подключись с ноутбука/телефона к WiFi **WRO-CAM**, пароль **wro2026fe**.
2. Открой **http://192.168.4.1** — там живая картинка, счётчики пикселей по
   каждому цвету и ползунки порогов (YCbCr: Y — яркость, Cb — «синева», Cr — «краснота»).
3. Ставь объект перед камерой → двигай ползунки, пока `px` объекта большой и
   стабильный, а на пустой сцене — ноль.
4. Камера: сначала сними галочки AEC/AGC/AWB и подбери exp/gain так, чтобы белый
   пол был белым (это аналог нашей фиксации экспозиции на OpenMV).
5. **Жми SAVE** — настройки сохраняются во флеш и переживают перезагрузку.

Порядок цветов на странице: RED, GREEN, ORANGE, BLUE, MAGENTA.

## 4. Калибровка дистанции (FOCAL)

1. Красный столбик ровно на **50 см** от объектива.
2. На странице смотри `RED ... h:<пиксели>`.
3. `focal = 50 * h / 10` → впиши в поле focal → SAVE.

## 5. Проверка связки с роботом

На ESP32-S3 в Serial Monitor должны пойти пакеты камеры (как раньше от OpenMV).
Если робот пишет camera offline — проверь: GPIO13→GPIO17, общий GND, 115200.

## 6. ⚠️ БОЕВАЯ СБОРКА (перед соревнованием)

В начале `espcam_vision.ino` поставить:

```cpp
#define ENABLE_WIFI_TUNER  0
```

и перепрошить. **Правила WRO запрещают радиосвязь на машине во время заезда.**
Пороги уже сохранены во флеше — после перепрошивки они остаются.

## Траблшутинг

| Симптом | Причина |
|---|---|
| `Brownout detector was triggered` в логе | Слабое питание 5V — толще провода, не от USB-хаба |
| `[CAM] init attempt N failed` | Шлейф камеры OV2640 не защёлкнут на плате |
| Быстро мигает красный LED | Камера не инициализировалась — робот уйдёт в failsafe (это правильно) |
| Редкое мигание LED | Всё работает, кадры идут |
| Пол «краснит» | Сузить RED по Cb (поднять Cbmin) и выключить AWB |

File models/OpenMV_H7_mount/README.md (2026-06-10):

# OpenMV Cam H7 Plus — Camera Mount · Team Faith

Front-of-platform mount that holds the **OpenMV Cam H7 Plus** on the flat top
of the electronics box (165 × 105 × 70 mm), aimed **forward and tilted down**
so the lens sees the track lines + pillars ahead of the car.

Capture style: **edge-capture cradle** — the board drops into a pocket and is
held by retention lips on the two sides + top edge. No reliance on the board's
M2.5 hole spacing (OpenMV does not publish it).

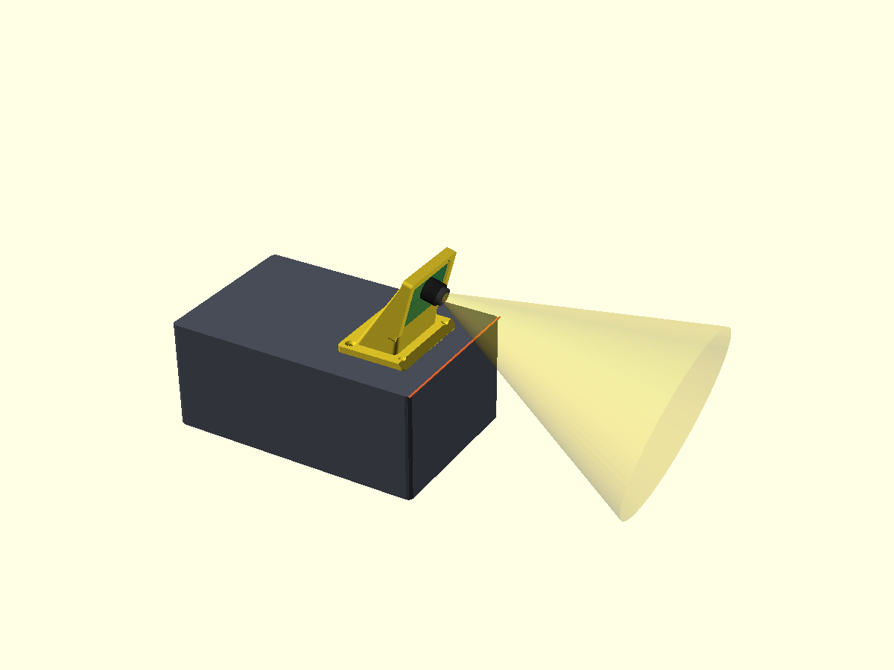
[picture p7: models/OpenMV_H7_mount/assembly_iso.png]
installed


---

## Files in this folder

| File | What it is | Tool |
|---|---|---|
| `openmv_h7_mount.scad` | **Printable part** — parametric source | OpenSCAD (free) |
| `openmv_h7_mount.stl`  | Pre-rendered mesh for the default sizes | any slicer |
| `assembly.scad` | Visual install: box + mount + ghost camera + FOV cone | OpenSCAD |
| `assembly_iso/side/top.png` | Renders for the engineering journal | — |
| `README.md` | This file | — |

> Export **`openmv_h7_mount.scad`** for slicing. `assembly.scad` is visual
> only — do **not** print it.

---

## OpenMV Cam H7 Plus — verified specs

| Spec | Value | Source |
|---|---|---|
| PCB outline | **45 × 36 mm** | openmv.io product page |
| Overall height | 29 mm (incl. M12 lens barrel) | openmv.io |
| PCB thickness | ~1.6 mm | standard |
| Sensor / optics | OV5640 on **M12 lens mount**, 2.8 mm lens | openmv.io |
| Mounting holes | 4 × **M2.5**, near corners | OpenMV forum |

⚠️ The H7 Plus PCB was laid out in Allegro by SingTown and OpenMV publishes
**no** mechanical drawing with hole-center spacing. The cradle therefore grips
the board **outline**, not its holes. If you want bolt-through instead, measure
the pattern yourself and set `BOLT_HOLES=true` + `BOLT_SP_L/W`.

---

## Step 1 — MEASURE before printing (critical)

Open `openmv_h7_mount.scad` and confirm these match calipers on your board:

```scad
CAM_L = 45.0;   // PCB long axis  (horizontal in the mount)
CAM_W = 36.0;   // PCB short axis (up the slope)
PCB_T = 1.6;    // PCB thickness
```

Edit + re-export if your board differs. Same rule as the AS5600 bracket.

---

## Step 2 — Set the aim

```scad
TILT_DEG = 15;   // lens downtilt below horizontal (10..30 typical)
```

This is a **fixed, printed** angle (most rigid, most repeatable). To change the
aim you re-print — there is no live hinge to drift under vibration. Start at 15°,
do a track-calibration run, and adjust:

- Sees too much sky / not enough near track → **increase** `TILT_DEG`
- Loses far pillars / sees mostly its own deck → **decrease** `TILT_DEG`

All other tunables (top of the file):

| Param | Default | Meaning |
|---|---|---|
| `BOARD_FIT` | 0.30 | pocket clearance — loosen/tighten board fit |
| `LIP_GRAB` | 2.0 | how far the lips wrap onto the board face |
| `PEDESTAL_H` | 10 | gap under the board for cable routing |
| `CABLE_W` | 14 | slot in the bottom edge for header wires / USB |
| `BASE_BACK/FRONT` | 40 / 6 | base reach (support behind, short at front) |
| `SCREW_*` | M3 | base mounting holes (countersunk) |

---

## Step 3 — Preview in OpenSCAD

```bash
# the installation view (box + camera + FOV)
open -a "OpenSCAD-2021.01" assembly.scad     # macOS
# or the printable part on its own
open -a "OpenSCAD-2021.01" openmv_h7_mount.scad
```

Press **F5** (preview). In the part file, set `SHOW_GHOSTS = true` to overlay
the camera + field-of-view cone. Press **F6** then *File → Export → STL* to slice.

---

## Step 4 — Print

| Setting | Value |
|---|---|
| Material | **PETG** (PLA creeps / softens near electronics) |
| Layer height | 0.2 mm |
| Infill | 40–50 % |
| Walls | 3–4 perimeters |
| Supports | **none** (geometry is self-supporting) |
| Orientation | base flat on the bed |

Print time ≈ 1 h.

---

## Step 5 — Install

1. **Mount to platform.** Sit the base at the **front** of the box top so the
   lens overhangs the front edge. Either:
   - bond with double-sided VHB tape (flat underside), **or**
   - mark + drill the 4 countersunk M3 holes into the box top and screw down.
2. **Insert the camera.** Tuck the board's bottom edge into the pocket first,
   then press the top edge under the top lip until it snaps in. The lens points
   forward through the open front; the bottom slot routes the UART header wires
   (TX/RX/GND/5V) down into the box toward the ESP32-S3 (UART2, GPIO 17/18).
3. **Confirm the view.** Power on, open the OpenMV IDE framebuffer, and check
   the camera sees the track lines + pillars where you expect. Adjust
   `TILT_DEG` and re-print if needed.

---

## Step 6 — Verify (vision side)

- Lens is **level side-to-side** (no roll) — image horizon should be flat.
- Re-check `src/openmv/openmv_main.py` focal constant + LAB color thresholds
  *after* the camera is at its final height/angle (per the characteristics
  audit — both are TRACK-CALIBRATION REQUIRED).
- If the image is upside-down or mirrored, fix in firmware with
  `sensor.set_vflip(True)` / `set_hmirror(True)` / `set_transpose(True)` rather
  than re-mounting.

---

## What this design deliberately does NOT do

- **No live tilt hinge** — a pivot drifts under vibration; a printed angle is
  repeatable. Re-print to re-aim.
- **No bolt-through by default** — the M2.5 hole spacing isn't published, so the
  cradle grips the outline. Bolt-through is available (`BOLT_HOLES=true`) only
  if you measure the pattern.
- **No enclosure over the lens** — keep the optics and the M12 focus ring free.

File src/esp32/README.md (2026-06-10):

# `src/esp32/` — Control firmware (ESP32-S3)

This is the control-system source for Team Faith's WRO v13 robot.
Compiled by the Arduino IDE using `esp32.ino` as the sketch entry point and
**one** `.cpp` file at a time selected by the `WRO_ACTIVE_TARGET` macro in
[`wro_build_target.h`](wro_build_target.h).

## How the build-target system works

The Arduino IDE compiles every `.cpp` file in this folder together. Each
`.cpp` that defines `setup()` / `loop()` wraps its body in
`#if WRO_ACTIVE_TARGET == WRO_TARGET_*` so that only **one** target's body
compiles. To switch targets, edit one line in `wro_build_target.h`:

```cpp
#define WRO_ACTIVE_TARGET WRO_TARGET_V13_MAIN   // ← change this
```

> ⚠️ The Arduino IDE does **not** recurse into subfolders.
> Files under [`legacy/`](legacy/) are kept for reference only and don't
> link into the active build. Diagnostic targets live at the root of this
> folder with a `diag_` filename prefix so they sort together but still
> compile.

## Build targets

| Target | File | Kind | Purpose |
|---:|---|---|---|
|  1 | `legacy/legacy_eps323.cpp` | LEGACY v11 | Original v11 race firmware (archived) |
|  2 | [`diag_scan_i2c_v13.cpp`](diag_scan_i2c_v13.cpp) | Diagnostic | Scan both I2C buses, list every address found |
|  3 | [`target_test_motor_servo_drive.cpp`](target_test_motor_servo_drive.cpp) | Diagnostic | Drivetrain bring-up (v11 code via root shim → `legacy/`) |
|  4 | `legacy/legacy_test_no_sensors.cpp` | LEGACY v11 | Open-loop timed lap (archived) |
|  5 | `legacy/legacy_test_servo.cpp` | LEGACY v11 | Servo sweep (archived) |
|  6 | `legacy/legacy_test_short_sequence.cpp` | LEGACY v11 | Short pattern (archived) |
|  7 | [`diag_test_servo_calibrate_v13.cpp`](diag_test_servo_calibrate_v13.cpp) | Diagnostic | Interactive steering-servo µs calibration (center / end-stops) |
|  8 | [`diag_test_encoders.cpp`](diag_test_encoders.cpp) | Diagnostic | 2× AS5600 on dual I2C — tick accumulation |
|  9 | [`diag_test_vl53l1x.cpp`](diag_test_vl53l1x.cpp) | Diagnostic | 2× VL53L1X with XSHUT address remap |
| 10 | [`diag_bench_test_v13.cpp`](diag_bench_test_v13.cpp) | Diagnostic | Full hardware sanity (IMU + encoders + ToF + servo + motor + camera + E-Stop) |
| 11 | [`wro_v13_main.cpp`](wro_v13_main.cpp) | **PRODUCTION** | v13 race firmware (Open + Obstacle Challenge) **← active** |

Recommended preflight sequence: **2 → 8 → 9 → 10 → 11**. See
[`../../docs/checklists/WRO_Robot_Master_Checklist_2026-03-27.md`](../../docs/checklists/WRO_Robot_Master_Checklist_2026-03-27.md)
for the step-by-step procedure.

## File layout (non-diagnostic, non-legacy)

The production firmware (`wro_v13_main.cpp`) is built on a layered architecture
spread across these files:

| Layer | Files |
|---|---|
| **HAL / drivers** | `as5600_dual_i2c.h`, `vl53l1x_dual.h`, `wro_hw_config_v13.h` |
| **Sensor wrappers** | `wro_imu.{cpp,h}`, `wro_sensors.{cpp,h}`, `wro_camera.{cpp,h}` |
| **Estimation** | `wro_odometry.{cpp,h}` |
| **Control** | `wro_pid.h`, `wro_corner.{cpp,h}`, `wro_park.{cpp,h}` |
| **Behavior** | `wro_behavior_open.{cpp,h}`, `wro_behavior_obstacle.{cpp,h}` |
| **Top-level FSM** | `wro_race_fsm.{cpp,h}`, `wro_estop.{cpp,h}` |
| **Telemetry** | `wro_telemetry.{cpp,h}` |
| **Tunables** | `wro_config_v13.h` ← edit here for PID gains, speeds, mode select |
| **Build switch** | `wro_build_target.h` ← edit here to change which target compiles |

## Required Arduino libraries

Install via Arduino IDE Library Manager:

- `Adafruit ICM20948` (and its `Adafruit BusIO` + `Adafruit Unified Sensor` deps)
- `ESP32Servo`
- `VL53L1X` by **Pololu** (not the ST/Adafruit forks — the API differs)

Board: **ESP32-S3 Dev Module** (Arduino-ESP32 core **v3.x** required — the
firmware uses the IDF 5 task-watchdog API (`esp_task_wdt_config_t` /
`esp_task_wdt_reconfigure`) and `ledcAttach`, which do not exist in 2.x).

## See also

- Wiring reference: [`../../docs/guides/WRO_Wiring_Map_v13.md`](../../docs/guides/WRO_Wiring_Map_v13.md)
- Assembly & first boot: [`../../docs/guides/WRO_Robot_Assembly_and_Startup_Guide.md`](../../docs/guides/WRO_Robot_Assembly_and_Startup_Guide.md)
- Telemetry CSV schema: [`wro_telemetry.cpp`](wro_telemetry.cpp) — emitted at 5 Hz from `wro_v13_main.cpp`
- Migration story (v11 → v12-planned → v13-actual): [`../../docs/strategy/WRO_Migration_v12_to_v13.md`](../../docs/strategy/WRO_Migration_v12_to_v13.md)

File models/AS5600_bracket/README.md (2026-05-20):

# AS5600 Encoder Bracket — Team Faith

Bracket + magnet-adapter set that fixes the shaking-encoder problem on the
WRO 2026 car. Three fabrication paths in one package — pick whichever your
team has tools for.

---

## Files in this folder

| File | What it is | Tool needed |
|---|---|---|
| `AS5600_bracket.scad` | Parametric 3D bracket source | OpenSCAD (free) |
| `magnet_adapter.scad` | Small centering disc for the magnet | OpenSCAD |
| `drawing.md` | Dimensioned drawing for hand-cut aluminium | Drill + vise |
| `README.md` | This file — assembly + verification |  |

---

## Why the encoder data was wrong

The AS5600 is a magnetic encoder. It reports a wrong angle when **any of these**
go out of spec:

1. **Air gap** between chip and magnet is not 0.5–3.0 mm
2. **Magnet polarity** is wrong (axial instead of diametric)
3. **Magnet off-centre** by >0.25 mm from the rotation axis
4. **Bracket flexes** under motor torque → gap changes dynamically while driving
5. **I²C wires** running parallel to motor wires picking up BTS7960 switching noise

Items 3, 4 and 5 are what almost certainly caused your "data is wrong" symptom.
The new bracket + adapter design fixes 3 and 4. You fix 5 by routing.

---

## Step 1 — Diagnose first (before building anything)

Run this BEFORE you fabricate. It tells you whether you need just the bracket,
or also a new magnet.

### 1a. Magnet polarity check

Hold a steel paperclip near the magnet:
- **Attracts to the SIDE** (edge) of the magnet → ✅ diametric — keep it
- **Attracts to the FACE** (flat top) → ❌ axial — replace with diametric

Diametric magnets are in your v12 shopping list — order 6×2.5 mm cylindrical
diametric type if you have any doubt.

### 1b. Magnet centering check (with current setup)

1. Flash build target 8 (`test_encoders.cpp`)
2. Open serial monitor at 115200 baud
3. Spin one wheel **very slowly** by hand — one full revolution in 5 seconds
4. Watch the raw angle output:
   - **Monotonic 0 → 4095 sweep** ✅ → magnet centered well enough
   - **Wobbles back and forth** (e.g. 100 → 150 → 130 → 200 → 180 → 250…) ❌
     → magnet off-centre → install the magnet adapter (Step 3)

### 1c. Air gap check

Use a feeler gauge or measure with calipers:
- Target: **1.5 mm** between AS5600 chip face and magnet face
- Acceptable: 0.5 – 3.0 mm
- Out of spec → bracket positioning is wrong → install new bracket (Step 4)

### 1d. I²C noise check

If 1a, 1b, 1c all pass but the data still glitches **only when motor runs**:
- Re-route SDA/SCL twisted pair away from the BTS7960 power wires
- Add ferrite beads on the I²C lines near the ESP32-S3
- Check 4.7 kΩ pull-ups are present on both Wire and Wire1 buses

---

## Step 2 — Measure your car (CRITICAL before printing)

Open `AS5600_bracket.scad` in OpenSCAD. The top of the file has 3 variables
you MUST verify match your car:

```scad
ARM_REACH = 28;   // distance: chassis side face → wheel INNER face
ARM_RISE  = 16;   // vertical: chassis-side anchor → axle centerline
AIR_GAP   = 1.5;  // sensor chip face → magnet face (target)
```

**How to measure:**

- **ARM_REACH** — with the car on its wheels, measure horizontally from the
  edge of the chassis plate to the inside face of the wheel hub.
  Use a small ruler or calipers. Typical HSP 94182 1/16: **24–30 mm**.

- **ARM_RISE** — measure vertically from the top of the chassis plate (where
  the bracket will bolt) up to the axle centerline (the imaginary line that
  goes through the wheel rotation centre). Typical HSP 94182: **14–18 mm**.

- **AIR_GAP** — keep at 1.5 mm. The slot on the sensor mount lets you tune
  this ±2 mm physically without re-printing.

Also verify these match your AS5600 board:

```scad
PCB_W            = 22;   // long axis of the purple breakout
PCB_H            = 18;   // short axis
PCB_HOLE_SPACING = 17;   // distance between the 2 M2 mounting holes
```

If your breakout is different, edit the numbers and re-export STL.

---

## Step 3 — Print the magnet adapter (do this first)

The adapter ensures the magnet stays centered on the rotation axis. Fixing
this often improves data quality more than fixing the bracket.

1. Open `magnet_adapter.scad` in OpenSCAD
2. Verify `MAGNET_D = 6.0` matches your magnet (measure with calipers)
3. Press **F6** to render, then **File → Export → Export as STL**
4. Slice with these settings:
   - Layer height: **0.12 mm** (precision pocket)
   - Infill: 100%
   - Walls: 4
   - No supports
5. Print **2 adapters** (one per rear wheel)
6. Drop a magnet into the pocket — should be snug, not loose, not forced.
   If too tight → reprint with `MAGNET_FIT = 0.20`
   If too loose → reprint with `MAGNET_FIT = 0.10`
7. **Verify diametric** (see Step 1a above)
8. Glue adapter to wheel hub centre with thin cyanoacrylate (super glue).
   - Clean wheel surface with isopropyl alcohol first
   - Apply a thin layer of glue to the flat bottom of the adapter
   - Press onto wheel centre, hold for 30 sec
   - Cure 1 hour before any driving

---

## Stability features (v1.1) — what makes this bracket actually rigid

A cantilever — even with one gusset — flexes under vibration. To stop the
shake we converted the cantilever into a **triangulated truss**. Four things
work together:

1. **Diagonal strut** (`STRUT_ENABLE=true` by default). Runs from the top of
   the sensor mount down to the bottom of the riser, in the same plane as
   the arm. The cantilever bending load on the sensor end becomes axial
   tension/compression in the strut — that's ~50× more efficient than
   bending a flat plate. **Single biggest rigidity improvement.**
2. **Deeper lateral arm** (`ARM_H=10`, was `BRACKET_T=4`). Bending stiffness
   scales with depth³ — going from 4 mm to 10 mm gives ~16× more rigidity
   for the same arm length.
3. **Double gussets** (`DOUBLE_GUSSET=true` by default). Triangular fillets
   on BOTH sides of the riser-to-arm corner — above the arm and below it.
   Together they make the corner rigid in torsion as well as bending.
4. **Back buttresses** (`BACK_BUTTRESS=true` by default). Small wedges that
   anchor the top and bottom edges of the sensor wall back to the lateral
   arm. The wall is taller than the arm by ~7 mm on each side; without
   buttresses those extensions would flap. With them, the wall is rigid.

If you find the bracket prints too bulky or interferes with something on
your specific car, you can disable individual features by editing the top
of `AS5600_bracket.scad` and setting `STRUT_ENABLE=false` etc. But the
default settings are what fixes the shake.

---

## Step 4 — Print or fabricate the bracket

### Option A — 3D print (recommended)

A pre-rendered `AS5600_bracket.stl` is already in this folder, sized for
the default measurements. If your car matches the defaults you can slice
this directly. Otherwise:

1. Open `AS5600_bracket.scad` in OpenSCAD
2. Verify `ARM_REACH`, `ARM_RISE`, `PCB_HOLE_SPACING` match your measurements
3. Set `SHOW_GHOSTS = false` at the bottom of the file (hides reference PCB/magnet)
4. **F6** to render, **File → Export → Export as STL**
5. In your slicer, **rotate the bracket so the anchor flange lies flat on the bed.**
   This makes the cantilever bending load perpendicular to layers = strongest.
6. Slice with:
   - Material: **PETG** (not PLA — PLA creeps under sustained load)
   - Layer height: 0.2 mm
   - Infill: **60%**
   - Walls: **4 perimeters**
   - No supports needed
7. Print **2 brackets** (one per rear wheel — mirror not needed, design is symmetric).
   Print time ~45 min per bracket.

### Option B — Hand-cut from aluminium

Follow `drawing.md` for the flat blank, fold lines, and gusset.
Use 2 mm aluminium sheet for best stiffness. 3 mm acrylic is OK as fallback
but will crack at the folds — score-and-snap with heat-bending instead.

### Option C — Laser-cut acrylic / plywood sandwich

Use the bracket SCAD to extract a top-view silhouette (project to 2D in
OpenSCAD), then cut 3 layers of 3 mm acrylic and stack with M2 standoffs.
This option is *less rigid* than 3D-print or aluminium — only use if it's
all you have access to.

---

## Step 5 — Install

### 5a. Mount bracket to chassis
1. Position the bracket against the side of the chassis at the rear-axle area
2. The 2× M3 holes in the anchor flange align with existing chassis holes
   (or drill new ones — chassis is plastic, easy)
3. M3 × 8 mm socket-head screws, thread into chassis tabs or use M3 nuts on
   the back
4. **Tighten firmly** — loose anchor screws are the #1 cause of bracket shake
5. Repeat on the other side

### 5b. Mount AS5600 PCB to bracket
1. Drop the purple AS5600 board into the sensor mount with the AS5600 chip
   facing OUT (toward the wheel — i.e. toward the magnet)
2. M2 × 8 mm screws go from the chassis side, through the slotted wall,
   through the PCB, with an M2 nut on the wheel side
3. **Leave the screws loose** for now — vertical alignment comes next

### 5c. Align chip vertically with axle centerline
The slots in the bracket wall let you slide the PCB up/down ±2 mm. The
AS5600 chip MUST sit directly over the wheel rotation axis.

1. With the wheel on the car and bracket installed, look from above
2. Slide PCB until the AS5600 chip (the small black square on the PCB) is
   centered over the wheel hub centerline (where the magnet is)
3. Tighten the 2× M2 nuts firmly

### 5d. Verify / fine-tune air gap
The air gap is set at PRINT time by the `AIR_GAP` parameter in the SCAD
(default 1.5 mm). After mounting:

1. Use a feeler gauge or calipers to measure actual air gap
2. If gap is **too small** (<1.0 mm): add an M2 washer between PCB and wall
   (each washer adds ~0.4 mm of gap)
3. If gap is **too large** (>2.5 mm): re-print the bracket with smaller
   `AIR_GAP` value (e.g. 1.0 mm)
4. Target final gap: **1.4–1.8 mm**

### 5e. Wire it up
- Wire and Wire1 buses per `wro_hw_config_v12.h`:
  - Left encoder: I²C bus 0 (GPIO 8/9) → 0x36
  - Right encoder: I²C bus 1 (GPIO 3/4) → 0x36
- Use **twisted pair** for SDA + GND, separate twisted pair for SCL + 3V3
- Route AS5600 cables **away from motor power wires** — at least 30 mm
  separation, or cross at 90° angles only
- Confirm 4.7 kΩ pull-ups present on both buses

---

## Step 6 — Verify (in this order — do not skip)

### 6a. I²C scan — confirm both AS5600s are seen
Flash build target 2 (`scanerI2C.cpp`). Expected output:

```
Wire (bus 0): 0x36 AS5600 left, 0x68 ICM-20948, 0x30 VL53L1X front
Wire1 (bus 1): 0x36 AS5600 right, 0x29 VL53L1X side
```

If 0x36 missing on either bus → wiring fault or board not powered. Fix
before continuing.

### 6b. Hand-spin smoothness — confirm magnet centering
Flash target 8 (`test_encoders.cpp`). Open serial at 115200. Spin each wheel
slowly by hand, one full revolution.

- Raw angle sweeps 0 → 4095 monotonically (no back-and-forth) ✅
- Wraps cleanly at 4095 → 0 ✅
- No "stuck" zones where the angle stops updating ✅

Failure modes:
- Wobble (non-monotonic) → magnet not centered → re-glue adapter
- Stuck at 0 or 4095 → air gap too big (magnet too weak) → tighten gap
- Stuck random value → air gap too small / magnet polarity wrong → re-check Step 1a

### 6c. Magnet quality — read MAGNITUDE register
The AS5600 has a built-in magnitude register that says how strong it sees
the magnetic field. Add this to your test loop:

```cpp
uint16_t magnitude = readAS5600Register(0x1B);  // MAGNITUDE register
Serial.printf("Magnitude: %d (target 1000-2500)\n", magnitude);
```

- 1000–2500 stable ✅
- <500 → gap too big or weak magnet
- >3500 → gap too small, magnet too close (saturation)
- Magnitude fluctuates >300 while wheel spins → BRACKET STILL FLEXING

### 6d. Bench test — wheels off ground at full motor speed
Flash target 10 (`bench_test_v12.cpp`). Lift wheels clear of ground.
Run motor at MOTOR_MAX_SPEED = 150 for 10 seconds. Log raw ticks at 100 Hz.

Expected: smooth monotonic increase, no jumps >50 counts per sample.
If you see jumps → bracket is still flexing under load → check anchor screw
tightness, add another gusset, or switch to aluminium bracket.

### 6e. Floor test — measured straight line
Drive the car **2.0 m** in a straight line on the floor (use a tape measure).
Convert encoder ticks to distance:

```
distance_cm = ticks / 277.4
```

(Where 277.4 comes from `TICKS_PER_CM` in `wro_hw_config_v12.h`)

- Within ±2% (1.96 – 2.04 m equivalent) ✅
- Larger error → wheel circumference miscalibrated (real wheel ≠ 47 mm OD)
  → measure actual wheel diameter and update `TICKS_PER_CM`

### 6f. Lap test — full WRO track
3 laps on actual WRO obstacle track. Watch left vs right encoder distance.
Difference should track only with steering arc (turns add to outer wheel,
subtract from inner). Erratic asymmetry = mechanical problem (slipping
magnet, loose bracket, gear lash if you went Solution 2).

---

## Troubleshooting cheat-sheet

| Symptom | Likely cause | Fix |
|---|---|-----|
| Bracket physically wobbles when you wiggle it with your fingers | Loose M3 anchor screws OR gusset missing/loose | Tighten M3s; re-bond gusset |
| Angle jumps wildly only when motor runs | Bracket flexes under torque | Add second gusset, or switch to aluminium |
| Angle jumps wildly even when stationary, just from touching the wire | I²C wire flaky | Re-solder header pins on AS5600 board |
| MAGNITUDE register reads <500 | Air gap too large or weak magnet | Reduce gap; check magnet is N52 not N35 |
| MAGNITUDE register reads >3500 | Magnet too close → saturation | Increase gap toward 2 mm |
| Sweep wobbles back-and-forth when spinning wheel slowly | Magnet off-centre | Re-glue with adapter (Step 3) |
| Both encoders read 0xFFFF (4095) always | Magnet polarity wrong (axial) | Replace with diametric magnet |
| One encoder fine, other dead | Wiring fault on one bus | Re-check Wire vs Wire1 connections |
| Sweep is jumpy but only at high speed | Sample rate too low for high RPM | Reduce LOOP_INTERVAL in config |

---

## What this design deliberately does NOT do

- **No fan-mounted vibration damping** — adding rubber under the bracket
  would just give it another resonance mode. Rigid all the way is correct.
- **No spring-loaded sensor** — fixed gap is more reliable than spring-pressed.
- **No magnetic shielding** — the AS5600 only cares about the rotating
  magnet, not stray fields from motor (those are at much higher frequencies
  and aren't strong enough to confuse a 12-bit angle).
- **No side anti-rotation pin** — if your bracket needs a pin to stay
  oriented, your screws are too loose. Tighten the screws.

---

## Open issues / future work

- If after all this the data is *still* glitchy under motor load, the
  fallback is Solution 2 (idler-pinion gear-drive encoder). That's an
  entirely different mechanical design and requires precision bearing
  machining — held in reserve only if Solution 1 fails despite proper
  bracket + adapter + wiring.
- Consider upgrading from 47 mm `TICKS_PER_CM` calibration to the actual
  measured wheel diameter after install. The HSP 94182 chassis model
  in `models/HSP94182_3D/chassis.scad` lists `WHEEL_D = 54` mm. Either
  the firmware or the SCAD is out of date — measure the real wheel and
  fix whichever is wrong.

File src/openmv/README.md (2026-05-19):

# `src/openmv/` — Vision firmware (OpenMV H7 Plus)

MicroPython firmware running on the OpenMV H7 Plus camera. Detects WRO 2026
field elements (orange/blue lap lines, red/green traffic-sign pillars, magenta
parking block) and streams a compact frame to the ESP32-S3 over UART at
115200 8N1, ~30 Hz.

## Files

| File | Purpose |
|---|---|
| [`openmv_main.py`](openmv_main.py) | Sole script. Deploy to the camera as `main.py` so it auto-runs on power-up. |

## What it sees

Per WRO 2026 Future Engineers rules (cited inline in the script):

| Object | Color | Rule | Real size |
|---|---|---|---|
| Lap line | Orange ≈ RGB(255,102,0) | 13.9 | 20 mm wide |
| Lap line | Blue ≈ RGB(0,51,255) | 13.9 | 20 mm wide |
| Traffic-sign pillar | Red ≈ RGB(238,39,55) | 13.21 | 50×50×100 mm |
| Traffic-sign pillar | Green ≈ RGB(68,214,44) | 13.22 | 50×50×100 mm |
| Parking-lot block | Magenta ≈ RGB(255,0,255) | 13.27 | 200×20×100 mm |

Distances to pillars and the parking block are estimated from blob height
in pixels using the pinhole-camera model (`d = FOCAL_PIX × 10 cm / blob_h_px`).

## UART frame

```
RedX,RedDist,GreenX,GreenDist,ModeFlag,ExtraTag*XX\n
```

Full schema (fields, ranges, bit assignments, XOR checksum):
[`../../docs/guides/WRO_OpenMV_UART_Protocol.md`](../../docs/guides/WRO_OpenMV_UART_Protocol.md).

> **v13 note:** Wall distance (bit 3 of `ModeFlag`) is reserved and always
> zero. The two VL53L1X ToF sensors on the ESP32-S3 own front-distance and
> side-distance — the camera no longer estimates wall range.

## Deploying to the camera

1. Connect the OpenMV H7 Plus over USB to the OpenMV IDE.
2. Run **Tools → Machine Vision → Threshold Editor** under the actual race
   lighting to dial in LAB thresholds for each color (rule 13.21/13.22/13.27
   RGBs are nominal — sensor + lighting drift them).
3. Paste the updated `(L,A,B)` tuples into the `*_THRESHOLD` constants near
   the top of `openmv_main.py`.
4. **File → Save Open Script to OpenMV Cam (As Main Script)**. The camera
   will execute `main.py` on every boot, no host required.

## Hardware wiring (camera side)

| OpenMV pin | Connects to | ESP32-S3 pin |
|---|---|---|
| P4 (UART3 TX) | UART2 RX on ESP32-S3 | GPIO 18 |
| P5 (UART3 RX) | UART2 TX on ESP32-S3 | GPIO 17 |
| 3.3V / GND | Logic supply | shared |

Authoritative wiring map: [`../../docs/guides/WRO_Wiring_Map_v13.md`](../../docs/guides/WRO_Wiring_Map_v13.md).

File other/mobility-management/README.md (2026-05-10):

# Mobility Management

How Team Faith's robot moves: drivetrain, steering, chassis, and the
control loops that turn sensor data into wheel motion.

---

## 1. Chassis

We built on top of an **HSP 94182** 1/16-scale RC car platform — a 4-wheel
independent-suspension chassis with a brushed motor and Ackermann steering.
This gave us a competition-proven mechanical base so we could focus our
engineering effort on electronics, sensing, and software.

- CAD reference: [`models/HSP94182_3D/`](../../models/HSP94182_3D/)
  ([viewer.html](../../models/HSP94182_3D/viewer.html) for an in-browser preview)
- Wheel diameter: 47 mm
- Track width: ~110 mm
- Wheelbase: ~165 mm

Custom 3D-printed mounts (designed in OpenSCAD, exported as STEP/STL) hold
the ESP32-S3, BTS7960 driver, OpenMV camera, IMU, ToF sensors, and the LiPo
battery. The OpenMV is mounted on an antenna mount looking forward, ~80 mm
above the floor — chosen so 100 mm pillars fit fully inside the QQVGA frame
between roughly 30 cm and 200 cm.

## 2. Drivetrain

| Component | Spec | Why |
|---|---|---|
| Motor | RS-540 brushed DC (HSP stock) | Ample torque, simple H-bridge control |
| ESC / driver | **BTS7960 43A H-Bridge** | Bidirectional, handles motor current with safety margin |
| Reduction | Stock 1/16 RC pinion + spur | Already gives suitable top speed for the 3 m WRO field |
| Wheels | 47 mm diameter rubber | Good grip on the WRO mat |

The BTS7960 is driven from the ESP32-S3 with two LEDC PWM channels
(R_PWM = forward, L_PWM = reverse) plus active-HIGH enable lines. Speed is
expressed as a signed integer in `[-255 .. +255]` and mapped to the two
channels in `wro_v13_main.cpp`'s motor mixer.

Rule 9.6 says the robot's drive system must be electrical and student-built
in the sense of integration; we satisfy this by integrating the off-the-shelf
HSP motor with our custom driver electronics and firmware.

## 3. Steering

| Component | Spec | Notes |
|---|---|---|
| Servo | **JX PDI-6221MG digital** | 20 kg·cm metal-gear, ~0.16 s / 60° |
| Linkage | Stock HSP Ackermann tie-rod | Reused from the donor RC car |
| Range | 45° (max-left) → 90° (centre) → 135° (max-right) | Software-limited to avoid mechanical bind |

The servo runs from a dedicated 5 V buck (separate from logic 5 V) so that
high-stall current dips do not brown out the ESP32-S3. Centre, end-stops
and microsecond mapping are tuned per chassis using the procedure in
[`docs/guides/WRO_Servo_Calibration_Guide.md`](../../docs/guides/WRO_Servo_Calibration_Guide.md)
and the standalone Arduino sketch
[`sketches/servo_calibrate/servo_calibrate.ino`](../../sketches/servo_calibrate/servo_calibrate.ino).

## 4. Speed control

Open Challenge runs at **PWM 80** maximum (steady, low slip), Obstacle
Challenge at **PWM 130** maximum (more aggressive, since the stop-and-turn
budget tolerates a bit more wheel-spin). Cornering — in either mode — drops
to **PWM 70** to keep slip out of the IMU yaw signal that drives turn exit.

Speed targets and ramps are defined as named tunables in
[`src/esp32/wro_config_v13.h`](../../src/esp32/wro_config_v13.h) so they
can be retuned without touching the FSM logic.

## 5. Closed-loop steering

We run two PID-style controllers in parallel, gated by the active mode:

- **Heading-hold (Open Challenge):** snaps to the nearest 90° heading after
  every corner exit, then holds against the IMU yaw with `KP = 12 µs/deg`,
  `KD = 2.0`, `KI = 0` (pure PD; integral was found unnecessary over a 3-min
  run and accumulated drift).
- **Pillar PID (Obstacle Challenge):** setpoint shifts ±60 px relative to
  the camera centre when a pillar of the active colour is in view (red →
  keep right, green → keep left). `KP = 0.45`, `KI = 0.001`, `KD = 0.30`
  with EMA-filtered derivative; integral is reset on colour switch.
  A far-pillar pre-position term at 0.4× gain blends in when both pillar
  colours are simultaneously visible.

The output of either PID is added to the servo centre value in
microseconds, clamped to the calibrated end-stops, and written to the
servo. Implementations: [`src/esp32/wro_pid.h`](../../src/esp32/wro_pid.h),
[`src/esp32/wro_v13_main.cpp`](../../src/esp32/wro_v13_main.cpp).

## 6. Cornering FSM

Cornering is owned by **VL53L1X front + IMU yaw delta**, never the camera
(an early v11 design used camera-gated turn entry and failed when the lens
was partially occluded mid-turn). The corner state is in
[`src/esp32/wro_corner.{h,cpp}`](../../src/esp32/wro_corner.cpp):

1. **Trigger:** front ToF < 350 mm for 3 consecutive frames.
2. **Slow-down:** front ToF < 600 mm starts a speed taper.
3. **Commit:** swing servo to maximum lock in the direction indicated by the
   most recent line colour (orange → CW, blue → CCW).
4. **Exit:** IMU yaw integrator passes 80° of delta from corner-entry yaw.
5. **Settle:** snap heading-hold target to the nearest 90° of the new
   absolute heading.

Encoder ticks during the turn are recorded as telemetry only; they are
*never* used as an exit condition (wheel slip during the turn would lie).

## 7. Engineering trade-offs

- **No I2C multiplexer.** The original v11 build used a TCA9548A to share
  one I2C bus across two AS5600s and two VL53L1Xs. The mux failed during
  practice. v13 drops it entirely and instead uses both native I2C
  peripherals on the ESP32-S3 (one AS5600 per bus) plus runtime XSHUT-based
  address remapping for the VL53L1X pair.
- **Brushed motor over brushless.** The stock HSP brushed motor is over-spec
  for 3 m WRO fields and avoids the BLDC commutation electronics we'd
  otherwise need to debug.
- **Single steering servo.** Rear-wheel drive + Ackermann front steering is
  geometrically appropriate for the corridor widths in the rules.

## See also

- Wiring map: [`docs/guides/WRO_Wiring_Map_v13.md`](../../docs/guides/WRO_Wiring_Map_v13.md)
- Assembly + startup: [`docs/guides/WRO_Robot_Assembly_and_Startup_Guide.md`](../../docs/guides/WRO_Robot_Assembly_and_Startup_Guide.md)
- Servo calibration: [`docs/guides/WRO_Servo_Calibration_Guide.md`](../../docs/guides/WRO_Servo_Calibration_Guide.md)
- Schemes: [`schemes/`](../../schemes/)

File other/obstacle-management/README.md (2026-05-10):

# Obstacle Management

How Team Faith handles the WRO Future Engineers **Obstacle Challenge**:
the strategy, the perception pipeline, and the FSM that turns red/green
pillars and a magenta parking block into safe, lawful manoeuvres.

---

## 1. The Obstacle Challenge in one paragraph

The arena is a 3 m × 3 m square track of corridors with four 90° corners.
The robot must complete **3 laps** while obeying coloured pillars: pass
**red on the right**, **green on the left**. After the third lap, in
the final corridor, the robot must perform a **parallel-parking manoeuvre**
between two magenta blocks. Direction (CW or CCW) is fixed at start by the
colour of the line under the start position (orange = CW, blue = CCW).
Mode selection is compile-time only (Rule 9.9): no physical switches.

## 2. High-level strategy

We treat Obstacle as **Open Challenge with a steering-target offset**:
the same heading-hold + corner FSM that drives Open is reused, and the
pillar logic only modifies the steering setpoint while a pillar is in
view. This keeps the firmware small and avoids two parallel control
codepaths fighting each other.

```
              ┌─────────────────┐
              │  WAIT_START     │  E-Stop press+release arms the run
              └────────┬────────┘
                       ▼
              ┌─────────────────┐
              │  RUN_OBSTACLE   │  heading-hold + pillar PID + corner FSM
              └────────┬────────┘
                       ▼
              ┌─────────────────┐
              │   TURN_90       │  IMU-driven, front-ToF gated
              └────────┬────────┘
                       ▼
                ... ×3 laps ...
                       ▼
              ┌─────────────────┐
              │   PARKING       │  approach → align → 3-phase reverse → final
              └────────┬────────┘
                       ▼
              ┌─────────────────┐
              │   FINISH        │  brake, stop, hold position
              └─────────────────┘

       SAFE_STOP runs in parallel; entered on E-Stop held or fault.
```

Top FSM: [`src/esp32/wro_race_fsm.cpp`](../../src/esp32/wro_race_fsm.cpp).
Obstacle behaviour: [`src/esp32/wro_behavior_obstacle.cpp`](../../src/esp32/wro_behavior_obstacle.cpp).

## 3. Perception pipeline

The OpenMV camera produces an ASCII v3 frame every ~20 ms. Inside the
ESP32-S3, a single read function in
[`src/esp32/wro_camera.cpp`](../../src/esp32/wro_camera.cpp) parses the frame
into a struct that the obstacle behaviour consumes:

| Field | Meaning |
|---|---|
| `redX` | Red-pillar centroid offset from image centre, in pixels (-80..+80) |
| `redDist` | Estimated red-pillar distance in cm, or 999 if absent |
| `greenX`, `greenDist` | Same, for green pillars |
| `modeFlag` | Bitfield: orange line / blue line / magenta block visibility |
| `extraTag` | X-position of magenta block when bit 2 is set |

Frames with bad checksum are dropped. Frames with implausible jumps
(distance > 80 cm change vs the previous valid frame) are dropped *once*
and then accepted on confirmation.

## 4. Pillar handling — the dynamic-offset PID

The setpoint of the steering PID is **shifted** when an active pillar is in
view, rather than turning around the pillar. Concretely:

- **Red pillar present** → PID setpoint += +60 px → robot drifts left until
  the visual centre of the pillar is offset 60 px to the right. Net effect:
  pass it on the right.
- **Green pillar present** → PID setpoint += -60 px → robot drifts right.
  Net effect: pass it on the left.
- **Both colours present:** the *near* colour controls the active offset.
  The *far* colour adds a small pre-position term (gain 0.4×) so the robot
  begins biasing in the right direction before it commits.
- **Pillar gone:** the offset returns to zero on the next loop and the
  PID integrator is reset to avoid carry-over wind-up from a manoeuvre
  that is now finished.

PID gains: `KP = 0.45`, `KI = 0.001`, `KD = 0.30` with EMA-filtered
derivative (`alpha = 0.30`). Tunables in
[`src/esp32/wro_config_v13.h`](../../src/esp32/wro_config_v13.h),
implementation in
[`src/esp32/wro_pid.h`](../../src/esp32/wro_pid.h).

The dynamic-offset approach is robust under partial occlusion and avoids
the discrete state explosion of a "swerve left / swerve right / pass /
return" sub-FSM.

## 5. Cornering interaction

Pillar logic and corner logic coexist by giving corners **priority**:
when the front VL53L1X reports < 350 mm for 3 frames, the FSM jumps to
`TURN_90` regardless of pillar state. PIDs are reset on corner exit so the
robot does not chase a stale pillar offset into the next corridor.

Corner exit is by **IMU yaw delta** (80°), never by camera. See
[`other/mobility-management/README.md`](../mobility-management/README.md#6-cornering-fsm)
for the full corner FSM.

## 6. Lap counting

Two independent counters provide redundancy:

- **Primary — gyro 360° accumulator.** The IMU yaw integrator wraps every
  full revolution; we increment on each wrap with hysteresis to avoid
  double-counting on small back-rotations.
- **Secondary — line crossings.** Each orange/blue line bit transition (on
  → off) bumps a counter, gated by a 1.5 s cooldown so a single line under
  the camera for several frames counts once.

The race FSM uses `max(gyroLaps, lineLaps)` and only exits `RUN_OBSTACLE`
to `TURN_90` *or* `PARKING` when both agree to within ±1.

## 7. Parallel parking (after lap 3)

Implemented in [`src/esp32/wro_park.cpp`](../../src/esp32/wro_park.cpp).

```
APPROACH  →  ALIGN  →  REVERSE_PHASE_1  →  REVERSE_PHASE_2  →  FINAL
```

| Phase | What we do |
|---|---|
| `APPROACH` | Drive forward at low PWM until the magenta block is centred (`abs(extraTag) < 15`) and within ~30 cm. |
| `ALIGN` | Continue 1 wheel-base past the block so the rear of the robot is aligned with the gap. |
| `REVERSE_PHASE_1` | Swing servo full lock toward the gap, drive in reverse until rear ToF reads ~10 cm to the rear block. |
| `REVERSE_PHASE_2` | Counter-steer to opposite full lock, continue reverse until front ToF clears the front block. |
| `FINAL` | Centre servo, low forward to settle, brake to FINISH. |

The phase machine aborts to `FINISH` if the camera goes silent (XOR fail
> 5 frames) — a parking miss is preferable to driving blind into the
arena edge.

## 8. Risk and rule-compliance summary

| Risk / rule | Mitigation |
|---|---|
| Wrong-side pass (rule violation) | Dynamic-offset sign is gated by colour bit; cannot be wrong if camera frame is valid. |
| Drift past corner exit | Yaw delta exit + heading-snap to 90° resets the absolute heading reference each corner. |
| Lap miscount | Two independent counters (gyro + camera) with consensus required. |
| Camera dropout in parking | FSM aborts to FINISH rather than driving blind. |
| Mode switch (rule 9.9) | Mode is a compile-time `#define OBSTACLE_MODE 1` — no physical switches. |
| E-Stop response | < 50 ms PWM-to-zero plus PID reset; documented in [`other/power-and-sense-management/`](../power-and-sense-management/) §3. |

Full rule mapping:
[`docs/strategy/WRO_Rule_Compliance_Matrix.md`](../../docs/strategy/WRO_Rule_Compliance_Matrix.md).

## See also

- OpenMV vision source: [`src/openmv/openmv_main.py`](../../src/openmv/openmv_main.py)
- UART protocol spec: [`docs/guides/WRO_OpenMV_UART_Protocol.md`](../../docs/guides/WRO_OpenMV_UART_Protocol.md)
- Race FSM: [`src/esp32/wro_race_fsm.cpp`](../../src/esp32/wro_race_fsm.cpp)
- Track test cases (each scenario with expected behaviour):
  [`docs/strategy/WRO_Track_Test_Cases.md`](../../docs/strategy/WRO_Track_Test_Cases.md)

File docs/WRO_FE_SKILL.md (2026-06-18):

---
name: wro-fe-team-faith
description: >
  Use this skill for ALL tasks related to Team Faith's WRO Future Engineers 2026 project.
  Trigger whenever the user mentions WRO, robot, ESP32, ESP32-S3, OpenMV, Pixy2, PID, servo, FSM, odometry,
  obstacle challenge, open challenge, firmware, sensors, I2C, SPI, UART, camera, encoders, checklist,
  preflight, tuning, competition, AS5600, VL53L1X, ICM-20948, engineering journal, or anything related to
  their autonomous car. This skill contains full project context so Claude can help without re-explanation.
---

# WRO Future Engineers 2026 — Team Faith Skill

## Project Overview
**Team:** Faith
**Competition:** World Robot Olympiad (WRO) Future Engineers 2026
**Category:** Self-Driving Cars (Open Challenge + Obstacle Challenge)
**Repo:** `https://github.com/Disfyy/WRO-Faith-Future-Engineer-`
**Local path:** `/Users/nr_ulan/Desktop/WRO_Project_Pack/`
**Active firmware:** v13 (ESP32-S3 + 2× AS5600 dual-I2C + 2× VL53L1X XSHUT-remap, no I2C mux)
**Active camera (2026-06):** **Pixy2** on UART2 — interim after the OpenMV OV5640 module was damaged ~5 days before competition. OpenMV + ESP32-CAM remain selectable fallbacks; all backends fill the same `g_cam` struct so the FSM/failsafes are backend-agnostic.

> **Status:** bench-test phase. `wro_build_target.h` currently selects `WRO_TARGET_BENCH_TEST` (10); switch to `WRO_TARGET_V13_MAIN` (11) for an actual race build.

---

## Hardware Stack (v13 — current)

| Component | Model | Role |
|---|---|---|
| Main Controller | ESP32-S3-DevKitC-1 N8R8 | PID, odometry, FSM, sensor fusion (dual-core, native USB) |
| Vision (active) | **Pixy2 / 2.1** (UART2) | Color-block tracking: pillars, lines, parking marker |
| Vision (fallback) | OpenMV H7 Plus / ESP32-CAM | Same UART2 link, same `g_cam` output |
| IMU | ICM-20948 (9-DoF) | Heading/yaw, lap counting |
| Encoders | 2× AS5600 magnetic (12-bit, dual I2C) | Odometry (~277 ticks/cm), one per native I2C peripheral |
| Front distance | VL53L1X (I2C, ~3 m Medium mode) | Corner detection + pre-emptive braking |
| Side distance | VL53L1X (I2C) | Wall-follow trim on Open Challenge straights |
| Motor Driver | BTS7960 43A H-Bridge | Drive motor (LEDC PWM, signed) |
| Steering | JX PDI-6221MG Digital Servo | Steering (50 Hz, µs-calibrated) |
| Power | 2S/3S LiPo + 5V step-down | Power supply |

> v12 was a planned migration to AS5048A SPI + TFMini-S; parts never arrived and the v11 TCA9548A I2C mux burned out. **v13** keeps the ESP32-S3 brain and reverts to the v11 sensor stack — 0x36 AS5600 collision solved by the bus split (one per native I2C peripheral), 0x29 VL53L1X collision solved by a boot-time XSHUT address-remap dance in `vl53l1x_dual.h`.

### ESP32-S3 Pin Map (v13 — authoritative: `wro_hw_config_v13.h`)
- **I2C0 (Wire), GPIO 8 / 9:** ICM-20948 (0x68) + AS5600 Left (0x36) + VL53L1X Front (0x29 → 0x30)
- **I2C1 (Wire1), GPIO 3 / 4:** AS5600 Right (0x36) + VL53L1X Side (0x29 → 0x31) — *moved from GPIO 11/12 in 2026-06; GPIO3 is a strapping pin but works for I2C*
- **VL53L1X XSHUT:** GPIO 15 (Front), GPIO 16 (Side), GPIO 47 (reserved 3rd)
- **UART2 (camera, Pixy2/OpenMV/ESP-CAM):** RX = 17, TX = 18, 115200 8N1
- **BTS7960 motor:** R_EN = 38, L_EN = 39, R_PWM = 40 (fwd), L_PWM = 41 (rev)
- **Steering servo:** GPIO 42
- **E-Stop:** GPIO 21 (INPUT_PULLUP) · **Status LED:** GPIO 2 · **RGB WS2812:** GPIO 48

### I2C Address Map (post-boot)
- **I2C0:** 0x68 (IMU), 0x36 (AS5600 L), 0x30 (VL53L1X F)
- **I2C1:** 0x36 (AS5600 R), 0x31 (VL53L1X S)
- AS5600 0x36 collision → sidestepped by the bus split. VL53L1X 0x29 collision → sidestepped by the boot-time XSHUT remap (front released, remapped to 0x30, then side released → 0x31). VL53L1X address is RAM-only, so the dance repeats every reset.

### Servo Calibration (bench-recal 2026-06-11, `wro_hw_config_v13.h`)
- `SERVO_CENTER_US = 1350`, `SERVO_LEFT_US = 1000`, `SERVO_RIGHT_US = 1700` (symmetric ±350 µs travel)
- `SERVO_MARGIN_US = 60` → safe limits `SERVO_LEFT_SAFE_US`/`SERVO_RIGHT_SAFE_US` keep the horn off the mechanical end-stops (end-stop stall = brownout). Re-measure with **target 7** (`diag_test_servo_calibrate_v13.cpp`).

---

## Software Architecture

### Two independent processors
1. **Vision (camera MCU):** `src/openmv/openmv_main.py` (OpenMV/ESP-CAM text path) and the on-ESP `wro_camera_pixy2.cpp` (Pixy2 binary block path). Both deliver: red/green pillars (X + distance), orange/blue line bits (lap direction), magenta parking block. Normalized into one `CameraData g_cam`. Protocol spec: `docs/guides/WRO_OpenMV_UART_Protocol.md`.
2. **Control (ESP32-S3, C++):** `src/esp32/wro_v13_main.cpp` — modular, layered. Race build = `WRO_TARGET_V13_MAIN` (11).

### Layered architecture (top-down only)
```
HAL          as5600_dual_i2c.h · vl53l1x_dual.h · ICM20948 lib · wro_i2c_buses.h
Estimation   wro_imu · wro_odometry · wro_sensors · wro_camera(+_pixy2)
Behavior     wro_corner · wro_behavior_open · wro_behavior_obstacle · wro_park
Control      wro_v13_main (steering mixer + speed ramp + steering-asymmetry trim)
FSM          wro_race_fsm (top) + wro_estop (parallel) + wro_telemetry(+_wifi)
```

### Camera data contract (`wro_camera.h`)
- `redX/greenX`: −80..79 px (cx−80 on a 160-px frame); "not seen" ⇒ `redDist/greenDist == 999`.
- `modeFlag` bits: `1`=orange line (CW), `2`=blue line (CCW), `4`=magenta parking. Bit 3 reserved (wall detection moved to VL53L1X in v13).
- `extraTag`: magenta block X (used to pick the parking-bay side).
- **Pixy2 signature order** (teach in PixyMon, this exact order): `1`=red pillar, `2`=green, `3`=orange line, `4`=blue line, `5`=magenta parking. **Set Data-out port = UART @ 115200** (factory default is 19200!).

---

## Round Logic — Top-Level Race FSM (`wro_race_fsm.cpp`)

Challenge is a **compile-time** flag only (Rule 9.9 — no physical switches): `OBSTACLE_MODE` in `wro_config_v13.h` (`0` = Open, `1` = Obstacle).

State enum order (also the telemetry `ST=` codes): `INIT(0) → WAIT(1) → RUN_O(2) | RUN_X(3) → [TURN(4) reserved] → PARK(5) → FIN(6)`, plus `STOP(7) = SAFE_STOP` (parallel).

| State | Behavior |
|---|---|
| **RS_INIT** | Servo centered, motor off. Advances to WAIT_START only when IMU+encoders healthy **and** the front VL53L1X booted (no front ToF ⇒ corner FSM never commits ⇒ wall crash). |
| **RS_WAIT_START** | Idle; optionally pre-rolls camera direction detection. On E-Stop **start** press: reset odo, rebase gyro-lap baseline + heading grid to current yaw, then enter `RUN_OPEN` or `RUN_OBS` per `OBSTACLE_MODE`. |
| **RS_RUN_OPEN** | Open Challenge straights + corners. Finishes at `lap ≥ TARGET_LAPS_RACE` (3) → FINISH. |
| **RS_RUN_OBS** | Obstacle Challenge straights + pillar avoidance + corners. Camera-silent > `CAM_SILENT_STOP_MS` (3 s) → SAFE_STOP. After lap 3 + magenta confirmed → PARKING. |
| **RS_PARKING** | Parallel-park sub-FSM. `park_done()`/`park_aborted()` → FINISH. |
| **RS_FINISH** | Stop, clear race-active. |
| **RS_SAFE_STOP** | Motor off immediately (not through ramp). Resumes the prior running state on E-Stop release (PIDs/corner reset, timeout clocks re-anchored); pre-race trap escapes back to WAIT_START. |

**Lap counter (`updateLapCounter`):** primary = gyro accumulator `|g_yaw_total − raceStartYawTotal| / GYRO_LAP_DEG(360)` with `LAP_COOLDOWN_MS` (3 s) between credits and a monotonic high-water mark (a crossing inside cooldown is credited late, never lost). Camera orange/blue line bit is a **secondary sanity check** within `LAP_LINE_GRACE_MS`, never the primary trigger.

**Direction detection (`detectDirection`):** votes once per **camera frame** (not per FSM tick); requires an *exclusive* color — orange→CW(+1), blue→CCW(−1) — held `DIRECTION_CONFIRM_FRAMES` (4) in a row; ambiguous frames decay both votes. Until confirmed, falls back to `DEFAULT_RACE_DIRECTION` (−1, CCW) and prints a one-shot warning if a corner starts unconfirmed.

### Corner sub-FSM (`wro_corner.cpp`) — runs *inside* RUN_OPEN/RUN_OBS
Distance-sensor + IMU only — **camera is never a corner trigger or exit** (that was the v11 turn failure).
`CN_ARMED → CN_SLOWDOWN → CN_COMMIT → CN_BRAKE → CN_EXECUTE → CN_EXIT → CN_LOCKOUT` (+ `CN_FAIL`).
- **Arm/slowdown:** front `< TURN_SLOWDOWN_MM` (600).
- **Commit:** front `< TURN_COMMIT_MM` (420 — matte-black walls only return valid frames ~420 mm) for `TURN_FRAMES_DEBOUNCE` (3) frames → capture `turnStartYaw`.
- **Brake-straight:** `TURN_BRAKE_MS` (100) at PWM 0.
- **Execute:** full lock toward `turnDirection` at `TURN_SPEED_PWM` (70 — slip is what cost the v11 turn). Exit when `|yaw − turnStartYaw| ≥ TURN_TARGET_DEG` (80°; heading-hold cleans the last ~10°). **Panic → CN_FAIL** if wall `< TURN_PANIC_MM` (100) or `> TURN_MAX_MS` (2500). `CN_FAIL` → race FSM SAFE_STOP.
- **Lockout:** suppress re-detect for `TURN_LOCKOUT_MS` (800) after exit. On exit it raises `g_corner_just_exited` so the race FSM snaps the new heading target to the 90° grid (anchored to race-start yaw, not absolute 0/90).

### Open Challenge behavior (`wro_behavior_open.cpp`)
Gyro heading-hold PID (`HEADING_KP 12 µs/°`, `KD 2`, `KI 0` — drift over 3 min) toward the post-corner snapped target. Optional **side-wall trim** (`HAS_SIDE_TOF=1`): hold `WALL_TARGET_MM` (100) with `WALL_KP 0.40`, clamped ±`WALL_TERM_CLAMP_US` (150); ignore side reads > `WALL_MAX_VALID_MM` (400 — randomized inner walls show 1–3 m across gaps). Sign convention: +yaw = CCW/left, larger µs = right ⇒ the heading term carries a **minus**.

### Obstacle Challenge behavior (`wro_behavior_obstacle.cpp`)
Pillar-avoidance PID on camera X. **Pass-side rule:** RED → vehicle passes the pillar's RIGHT, so hold the pillar **left** of center (setpoint `−PILLAR_OFFSET_PX`, −30 px); GREEN → passes LEFT, hold pillar **right** (+30 px). Gains `PILLAR_KP 0.45 / KI 0.001 / KD 0.30` (EMA-filtered derivative, α 0.30); reset integral on color switch; pick the **closer** pillar, add a `PILLAR_FAR_GAIN` (0.40) pre-position term from the far pillar. No pillar → blend toward heading-hold over `PILLAR_BLEND_OUT_MS` (250). Hard brake if front `< PILLAR_SAFETY_FRONT_MM` (200).

### Parking sub-FSM (`wro_park.cpp`) — Obstacle only, after lap 3
Triggered when `lap ≥ 3` **and** magenta seen `PARK_MAGENTA_CONFIRM` (5) camera frames in a row **and not mid-corner**.
`PK_APPROACH → PK_ALIGN → PK_REV_A → PK_REV_B → PK_REV_C → PK_FINAL` (+ `PK_ABORT`).
- **APPROACH:** heading-hold creep forward; pick bay side from magenta X (`extraTag` sign); stop at back-wall (front < 250 mm). Timeout `PARK_APPROACH_MAX_MS` (6 s) → ABORT.
- **ALIGN:** wait until yaw-rate `< PARK_ALIGN_RATE_DPS` (2 °/s) for 200 ms; `PARK_ALIGN_MAX_MS` (4 s) timeout proceeds anyway (gyro bias may never settle after a 3-min run).
- **REV_A:** reverse + steer into bay `PARK_PHASE_A_CM` (25, encoder-measured).
- **REV_B:** counter-steer until heading aligns (or `PARK_PHASE_B_MS` 1500 cap).
- **REV_C:** straight back until `PARK_PHASE_C_CM` (45 total) **or** front clears > `PARK_FRONT_CLEAR_MM` (350). Steering sign **flips to +** here (reversing inverts the steer↔yaw relation).
- Phase completion is **encoder-distance** based; the `*_MS` values are failsafe caps that survive an E-Stop pause via `park_shift_clock()`.

---

## Key Tunables (`src/esp32/wro_config_v13.h`)
```cpp
OBSTACLE_MODE        0      // 0 = Open, 1 = Obstacle (the ONLY mode switch — Rule 9.9)
HAS_SIDE_TOF         1      // side VL53L1X wired by default in v13
DEFAULT_RACE_DIRECTION (-1) // fallback until camera locks orange/blue (-1=CCW, +1=CW)

TURN_SLOWDOWN_MM     600
TURN_COMMIT_MM       420    // was 350 — matte-black walls only return valid frames ~420 mm
TURN_TARGET_DEG      80
TURN_SPEED_PWM       70     // slip-limited
OPEN_MAX_PWM         65     // testing value for short black-wall range; raise toward 80 via S+
OBS_MAX_PWM          130
SPEED_RAMP_STEP      8      // PWM/10 ms · MIN_DRIVE_PWM 35 deadband floor
PILLAR_OFFSET_PX     30     // camera X is ±80, not ±160
PILLAR_KP 0.45 / KI 0.001 / KD 0.30 (EMA 0.30)
HEADING_KP 12.0 / KD 2.0 / KI 0.0
STEER_GAIN_LEFT/RIGHT 1.00  // steering asymmetry trim (live-tune L/R, clamp 0.5..1.5)
TARGET_LAPS_RACE     3      // GYRO_LAP_DEG 360, LAP_COOLDOWN_MS 3000
LOOP_INTERVAL_MS     10     // WDT_TIMEOUT_MS 200 (hardware task watchdog)
ESTOP_BYPASS_AUTOSTART 0    // BENCH-ONLY — MUST be 0 for any run that can move
WIFI_TELEMETRY       1      // TESTING-ONLY — MUST be 0 for competition (Rule 11.10)
CAMERA_BACKEND       PIXY2  // revert to OPENMV if the OpenMV module is revived
```

---

## Repository Structure (v13)
```
src/esp32/
  wro_v13_main.cpp         # active main firmware (target 11): setup/loop, steering+motor write, ramp
  wro_race_fsm.{cpp,h}     # top-level race FSM + lap/direction logic
  wro_corner.{cpp,h}       # cornering sub-FSM (distance + IMU)
  wro_behavior_open.{cpp,h}     # Open Challenge heading-hold + wall trim
  wro_behavior_obstacle.{cpp,h} # Obstacle pillar-avoidance PID
  wro_park.{cpp,h}         # parallel-park sub-FSM
  wro_estop.{cpp,h}        # E-Stop / start-button logic (parallel)
  wro_imu.{cpp,h} wro_odometry.{cpp,h} wro_sensors.{cpp,h}  # estimation
  wro_camera.{cpp,h}       # OpenMV/ESP-CAM UART text parser → g_cam
  wro_camera_pixy2.cpp     # Pixy2 binary block parser → g_cam (active backend)
  wro_steering_comp.h      # steering asymmetry trim
  wro_telemetry.{cpp,h}    # 5 Hz telemetry + USB live-tune commands
  wro_telemetry_wifi.{cpp,h} # Wi-Fi UDP mirror (testing only; no-op when WIFI_TELEMETRY=0)
  wro_pid.h wro_i2c_buses.h
  wro_hw_config_v13.h      # pin map + addresses + servo cal + odometry
  wro_config_v13.h         # tunables + OBSTACLE_MODE + HAS_SIDE_TOF + CAMERA_BACKEND
  wro_build_target.h       # target selector
  as5600_dual_i2c.h vl53l1x_dual.h  # HAL drivers
  diag_*.cpp               # bench/test targets (see below)
  legacy/                  # v11 archived sources (targets 1,4,5,6)
src/openmv/openmv_main.py  # MicroPython vision (OpenMV/ESP-CAM path)
docs/  schemes/  models/   # guides+checklists+logs / wiring / CAD (+ models/Pixy2_mount/)
```

### Build Targets (`wro_build_target.h`)
| # | Target | Notes |
|---|---|---|
| 2 | SCAN_I2C | both buses — `diag_scan_i2c_v13.cpp` |
| 3 | TEST_MOTOR_SERVO_DRIVE | v11 code via root shim |
| 7 | TEST_SERVO_CAL | v13 — `diag_test_servo_calibrate_v13.cpp` |
| 8 | TEST_ENCODERS | AS5600 dual I2C |
| 9 | TEST_VL53L1X | front + side, XSHUT remap |
| 10 | BENCH_TEST | all sensors + actuators ← **currently active** |
| 11 | V13_MAIN | race firmware (Open + Obstacle) |
| 12 | TEST_CAMERA | UART2 link/frame/checksum verdict |
> Targets 1, 4, 5, 6 are archived v11 in `src/esp32/legacy/`.

---

## Live Tuning over USB Serial (115200, newline-terminated)
- `P0.45` / `I0.001` / `D0.30` — pillar PID gains
- `G12.0` — heading PID Kp
- `L1.15` / `R1.00` — steering asymmetry trim (clamped 0.5..1.5)
- `S+` / `S-` — bump both max speeds ±5 (clamped to [deadband, 255])
- `?` — full state dump · `!` — software E-Stop
- Telemetry line (5 Hz, mirrored to Wi-Fi UDP when enabled):
  `T=… ST=… CN=… LAP=… YAW=… DST=L±/R± TF=…mm CAM=R(x,d)/G(x,d) PWM=± ST=…us`

---

## Failsafes (v13)
- **Hardware task watchdog** 200 ms — loop hang (I2C lock-up, library stall) → panic reset instead of a motionless/runaway robot.
- **Front-ToF death** mid-race: silent > `TF_FRONT_DEAD_MS` (3 s) → SAFE_STOP (corner FSM can't commit without it).
- **Sensor health:** IMU or encoder failure → SAFE_STOP (outside INIT/FINISH).
- **Camera silence (Obstacle):** offline > 3 s → SAFE_STOP; during APPROACH > 500 ms → park ABORT.
- **Brownout proxy:** |PWM| > deadband but speed < 5 cm/s too long → warn.
- **E-Stop:** hardware GPIO 21 (debounced, 500 ms boot grace) **and** software `!`. Immediate motor cut, resumes on release.
- **Rule 11.10:** `WiFi.mode(OFF)` + `btStop()` at boot. `WIFI_TELEMETRY` must be 0 for competition; testing AP = `WRO-FAITH`.

---

## Pre-Flight Sequence (v13, always before run)
1. **Target 2** SCAN_I2C — I2C0 shows 0x68 + 0x36 + 0x30; I2C1 shows 0x36 + 0x31. (0x70 = old TCA9548A, must be GONE.)
2. **Target 8** TEST_ENCODERS — both AS5600 accumulate ticks (one per bus).
3. **Target 9** TEST_VL53L1X — front + side return real mm at remapped addresses.
4. **Target 12** TEST_CAMERA — UART2 frames/blocks flowing, checksum/decode OK (current backend = Pixy2).
5. **Target 10** BENCH_TEST — IMU + encoders + VL53L1X + motor + servo + camera + E-Stop all live.
6. **Target 11** V13_MAIN — wheels-up smoke: heading-hold rotates servo as the chassis is turned by hand.
7. Test E-Stop physically (immediate stop + clean resume); confirm steering centered + motor direction.
8. Wheels off ground first, then floor test. Confirm `ESTOP_BYPASS_AUTOSTART 0` and `WIFI_TELEMETRY 0` for competition.

---

## Common Failure Modes & Fixes (v13)
| Problem | Fix |
|---|---|
| I2C scan finds wrong devices | Expect 0x68+0x36+0x30 on I2C0, 0x36+0x31 on I2C1. 0x70 = dead mux. Check I2C1 is on GPIO 3/4 (moved from 11/12). |
| AS5600 reads −1 / 0 / 4095 | Wrong bus (Wire vs Wire1), magnet gap (0.5–3 mm), polarity, 3.3 V, 4.7 kΩ pull-ups. |
| VL53L1X stuck at 0x29 / never comes up | XSHUT order: front must boot + remap to 0x30 before side is released. Drive XSHUT HIGH only after `setBus()`, before `init()`. |
| Camera frame/decode fail | Backend = Pixy2: UART @ 115200 (not 19200), signature order 1–5, RX/TX crossed, common GND. Distance jump-defense rejects sudden jumps. |
| Robot under/over-rotates corners | Tune `TURN_TARGET_DEG` / `TURN_SPEED_PWM`. NEVER use encoder ticks or camera as the corner exit. |
| Corner aborts (CN_FAIL/panic) on black walls | Valid front frames start ~420 mm; keep `TURN_COMMIT_MM` ≈ 420 and approach slow (`OPEN_MAX_PWM` ~65). |
| Turns weaker one way | Move LiPo (corner-weight) first, then trim with `STEER_GAIN_LEFT/RIGHT` (L/R live). Expect 1.10–1.25, never 2.0. |
| Strong oscillation on straights | Lower `HEADING_KP`, raise `HEADING_KD`, reduce speed. |
| Heading drift over 3 min | ICM-20948 gyro Z drifts with motor heat; snap-to-90° after each corner mitigates. Re-cal on a still surface. |

---

## How Claude Should Help
- Always reference real paths in `/Users/nr_ulan/Desktop/WRO_Project_Pack/`; read `wro_hw_config_v13.h`, `wro_config_v13.h`, `wro_v13_main.cpp` before answering hardware/code questions.
- Treat **v13** as current. Treat `src/esp32/legacy/legacy_*.cpp` and any v11/v12 references in older docs as historical.
- Remember the active camera backend is **Pixy2** (`CAMERA_BACKEND_PIXY2`); OpenMV/ESP-CAM are fallbacks feeding the same `g_cam`.
- Remember I2C topology: AS5600 L + IMU + VL53L1X Front on Wire (I2C0, GPIO 8/9); AS5600 R + VL53L1X Side on Wire1 (I2C1, **GPIO 3/4**). VL53L1X addresses are remapped at boot (all start at 0x29).
- Cornering trigger/exit must stay **distance-sensor + IMU** based — do NOT regress to camera-gated triggers or encoder-distance exits.
- Use the v13 tunables above; follow the pre-flight target order (2 → 8 → 9 → 12 → 10 → 11).
- Keep WRO rule compliance in mind: Rule 9.9 (compile-time mode only), single start button, Rule 11.10 (no wireless during runs — `WIFI_TELEMETRY 0`).
- Suggest logging results to the CSV files in `docs/logs/`; push engineering-journal time (worth points) and practice runs.

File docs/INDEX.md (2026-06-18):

# Documentation Index

A single page that lists every document in this repository, grouped by
purpose. If you are a WRO judge or a new teammate, this is the fastest
way to find what you need.

## Top-level

| Path | Purpose |
|---|---|
| [`../README.md`](../README.md) | Project overview, hardware summary, software architecture, quick setup |
| [`../CHANGELOG.md`](../CHANGELOG.md) | Versioned engineering history (v11 → v12 plan → v13 actual) |
| [`README.md`](README.md) | `docs/` folder navigation hub |

## Engineering writeups by topic — `../other/`

These are the WRO-rubric-aligned summaries; each one links out to the
canonical sources of truth.

| Topic | Writeup |
|---|---|
| Mobility (drivetrain / steering / chassis / control loops) | [`../other/mobility-management/README.md`](../other/mobility-management/README.md) |
| Power and sensing (battery, power dist., sensor stack) | [`../other/power-and-sense-management/README.md`](../other/power-and-sense-management/README.md) |
| Obstacle Challenge strategy (perception, FSM, parking) | [`../other/obstacle-management/README.md`](../other/obstacle-management/README.md) |

## Engineering reference — `guides/`

| Document | What it covers |
|---|---|
| [`guides/WRO_Wiring_Map_v13.md`](guides/WRO_Wiring_Map_v13.md) | Authoritative pin map for the v13 (ESP32-S3) build |
| [`guides/WRO_Robot_Assembly_and_Startup_Guide.md`](guides/WRO_Robot_Assembly_and_Startup_Guide.md) | Physical build steps + first power-on |
| [`guides/WRO_Servo_Calibration_Guide.md`](guides/WRO_Servo_Calibration_Guide.md) | Servo center / end-stop / µs-mapping procedure |
| [`guides/WRO_OpenMV_UART_Protocol.md`](guides/WRO_OpenMV_UART_Protocol.md) | Camera-to-ESP32 frame format spec (v3, original/fallback OpenMV backend) |
| [`guides/WRO_Pixy2_Setup.md`](guides/WRO_Pixy2_Setup.md) | Pixy2/2.1 signature teaching + UART config (active camera backend) |

## Race-day operations — `checklists/`

| Document | When to use it |
|---|---|
| [`checklists/WRO_Quick_Race_Checklist.md`](checklists/WRO_Quick_Race_Checklist.md) | 5-minute pre-run sanity pass |
| [`checklists/WRO_Robot_Master_Checklist_2026-03-27.md`](checklists/WRO_Robot_Master_Checklist_2026-03-27.md) | Full preflight — first run of the day or after major changes |
| [`checklists/WRO_Preflight_Log.md`](checklists/WRO_Preflight_Log.md) | Fillable run-by-run log template |

## Strategy and analysis — `strategy/`

| Document | Content |
|---|---|
| [`strategy/WRO_Migration_v12_to_v13.md`](strategy/WRO_Migration_v12_to_v13.md) | Why v12 (AS5048A SPI + TFMini-S) was abandoned and how v13 was assembled |
| [`strategy/WRO_Rule_Compliance_Matrix.md`](strategy/WRO_Rule_Compliance_Matrix.md) | Per-rule mapping to firmware/hardware (line refs v11; needs v13 re-audit) |
| [`strategy/WRO_Characteristics_Audit_2026-04-09.md`](strategy/WRO_Characteristics_Audit_2026-04-09.md) | Historical audit of template-vs-runtime values (v11 lines, archival) |
| [`strategy/WRO_Track_Test_Cases.md`](strategy/WRO_Track_Test_Cases.md) | Structured test scenarios with expected behaviour |
| [`strategy/WRO_Risk_Register.md`](strategy/WRO_Risk_Register.md) | Identified risks + mitigations |
| [`strategy/WRO_Release_Notes_Template.md`](strategy/WRO_Release_Notes_Template.md) | Template for tagging firmware releases |
| [`strategy/WRO_Config_Template.h`](strategy/WRO_Config_Template.h) | Reference list of tunables (v11 vintage; cross-check against `src/esp32/wro_config_v13.h`) |

## Running logs — `logs/`

| Log | What's recorded |
|---|---|
| [`logs/WRO_PID_Tuning_Log.csv`](logs/WRO_PID_Tuning_Log.csv) | Each PID gain change + observed behaviour |
| [`logs/WRO_Maintenance_Log.csv`](logs/WRO_Maintenance_Log.csv) | Hardware swaps, repairs, soldering events |
| [`logs/WRO_Test_Log.csv`](logs/WRO_Test_Log.csv) | Per-run lap times and incidents |

## Competition reference — `rules/`

| Document | Content |
|---|---|
| [`rules/WRO-2026-Future-Engineers-Self-Driving-Cars-General-Rules.md`](rules/WRO-2026-Future-Engineers-Self-Driving-Cars-General-Rules.md) | Markdown copy of the official rules |
| [`rules/WRO-2026-Future-Engineers-Self-Driving-Cars-General-Rules.pdf`](rules/WRO-2026-Future-Engineers-Self-Driving-Cars-General-Rules.pdf) | Original PDF |

## Internal / meta

| Document | Purpose |
|---|---|
| [`WRO_FE_SKILL.md`](WRO_FE_SKILL.md) | Project-context document used by Claude Code as a "skill" file |

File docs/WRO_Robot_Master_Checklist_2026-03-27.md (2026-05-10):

# WRO Future Engineers — Robot Master Checklist

Date: 9 April 2026 (initial) | Updated to v13 hardware: 9 May 2026
Team: ____________________
Robot Version: ____________________
Firmware Version: ____________________

> **v13 hardware (May 2026):** ESP32-S3 + 2× AS5600 (dual native I2C) + 2× VL53L1X (XSHUT addr-remap) + ICM-20948 IMU + OpenMV H7 Plus + BTS7960 + JX servo. **No TCA9548A multiplexer** (the original v11 mux burned out). The address conflicts are resolved by splitting the AS5600s across `Wire`/`Wire1` and remapping VL53L1X addresses at boot. For race day, also use [`WRO_Quick_Race_Checklist.md`](WRO_Quick_Race_Checklist.md) and [`WRO_Preflight_Log.md`](WRO_Preflight_Log.md).

---

## 1) Purpose
Use this checklist before every test and race run to confirm the robot is safe, rule-compliant, and stable.

---

## 2) Compliance references

- Official rules: `docs/rules/WRO-2026-Future-Engineers-Self-Driving-Cars-General-Rules.pdf`
- Rule mapping: `docs/WRO_Rule_Compliance_Matrix.md`
- Characteristics audit: `docs/WRO_Characteristics_Audit_2026-04-09.md`
- Main build / operation guide: `docs/WRO_Robot_Assembly_and_Startup_Guide.md`

---

## 3) Hardware required (minimum)

### Controller and logic (v13)
- ESP32-S3-DevKitC-1 N8R8 (USB-C, native USB-OTG)
- ICM-20948 IMU (on I2C0 with AS5600 Left + VL53L1X Front)
- AS5600 magnetic encoder × 2 (one on each native I2C bus, fixed `0x36`)
- VL53L1X distance sensor × 2 (one on each I2C bus, default `0x29` → remapped at boot)
- OpenMV H7 Plus (UART2)

### Motion and power
- BTS7960 motor driver
- DC drive motor
- Steering servo JX PDI-6221MG
- LiPo 7.4 V + LM2596 step-down to 5 V (and optional 3.3 V)
- One main power switch (KCD3)
- E-Stop button (GPIO 21, INPUT_PULLUP, active LOW)

### Wiring and mechanics
- Quality wires, crimped connectors
- Common GND between ESP32-S3, BTS7960, sensors, camera (star ground)
- Sensors mounted with vibration reduction
- Servo horn aligned at the mechanical center

---

## 4) Required wiring map (must match firmware)

### ESP32-S3 pins (v13)
- **I2C0 SDA:** GPIO 8
- **I2C0 SCL:** GPIO 9
- **I2C1 SDA:** GPIO 11
- **I2C1 SCL:** GPIO 12
- **VL53L1X Front XSHUT:** GPIO 15
- **VL53L1X Side XSHUT:** GPIO 16
- **VL53L1X Third XSHUT (reserved):** GPIO 47
- **OpenMV camera RX:** GPIO 17
- **OpenMV camera TX:** GPIO 18
- **BTS7960 R_EN:** GPIO 38
- **BTS7960 L_EN:** GPIO 39
- **BTS7960 R_PWM:** GPIO 40 (LEDC Ch0 — forward)
- **BTS7960 L_PWM:** GPIO 41 (LEDC Ch1 — reverse)
- **Steering servo:** GPIO 42
- **E-Stop:** GPIO 21
- **Status LED:** GPIO 2
- **Onboard RGB LED:** GPIO 48

### I2C0 (Wire) device map
- ICM-20948 IMU at `0x68` (AD0 → GND)
- AS5600 Left at `0x36`
- VL53L1X Front: `0x29` at boot → `0x30` after remap

### I2C1 (Wire1) device map
- AS5600 Right at `0x36`
- VL53L1X Side: `0x29` at boot → `0x31` after remap

> **No `0x70`** — the TCA9548A is gone in v13.

---

## 5) Software / library requirements

### Arduino IDE
- ESP32 board package (Espressif v3.x)
- Board: **ESP32S3 Dev Module**
- USB CDC On Boot: **Enabled**
- Flash Size: **8MB**, PSRAM: **OPI PSRAM**
- Serial Monitor at 115200 baud

### Libraries
- Wire (built-in)
- ESP32Servo
- Adafruit ICM20948
- Adafruit Unified Sensor
- **VL53L1X by Pololu** (new in v13)
- (AS5600 driver is inline in `as5600_dual_i2c.h` — no library install)

### Active code files (v13)
- `wro_v13_main.cpp` (main race firmware — target 11)
- `scan_i2c_v13.cpp` (dual-bus diagnostic scanner — target 2)
- `test_encoders.cpp` (AS5600 dual-I2C test — target 8)
- `test_vl53l1x.cpp` (VL53L1X with XSHUT remap — target 9)
- `bench_test_v13.cpp` (full bench — target 10)
- `src/esp32/legacy/legacy_eps323.cpp` and other `legacy_*.cpp` (v11 reference, archived, not active)

### Key protocol file
- `WRO_OpenMV_UART_Protocol.md` (v3.0 — 6 fields + XOR checksum)

---

## 6) Safety requirements (non-negotiable)

| Requirement | Acceptance criteria | If FAIL |
|---|---|---|
| E-Stop works in all states | Pressing E-Stop forces `RS_SAFE_STOP`; motor = 0; steering centered | Stop testing; fix GPIO 21 wiring and debounce path |
| Startup is safe | On boot, robot stays in `RS_INIT`/`RS_WAIT_START` with motor = 0 | Block run; inspect startup transitions |
| Camera-loss fail-safe | Warning after camera timeout (500 ms) and full SAFE_STOP if offline > 3000 ms | Block run; inspect UART2 + camera power |
| Encoder-loss fail-safe | Persistent encoder loss (50 consecutive errors) → SAFE_STOP | Block run; inspect AS5600, magnets, I2C wiring |
| Wheels-off-ground first | Initial verification on a stand | Do not move to floor tests |

---

## 7) Pre-flight procedure (every run)

### Step A — Visual and electrical
- Check connectors for looseness
- No exposed shorts
- Battery voltage in range (LiPo 7.0–8.4 V)
- Common GND continuity (multimeter: 0 Ω between every GND)

If FAIL → fix immediately and rerun Step A.

### Step B — Sensor bus check (v13)
1. Set `WRO_ACTIVE_TARGET = WRO_TARGET_SCAN_I2C` (target 2) → upload `scan_i2c_v13.cpp`.
2. Confirm:
   - **I2C0:** `0x68` + `0x36` + `0x29`
   - **I2C1:** `0x36` + `0x29`
   - **No `0x70`** — that would mean a TCA9548A is still on the bus (it shouldn't be in v13).
3. Run target 8 (`test_encoders.cpp`): both AS5600s sweep 0–4095, ticks accumulate.
4. Run target 9 (`test_vl53l1x.cpp`): both VL53L1X come up at remapped addresses (`0x30`, `0x31`) and report distances.
5. If anything mismatches, stop and verify wiring against [`docs/WRO_Wiring_Map_v13.md`](WRO_Wiring_Map_v13.md).

### Step C — Main firmware check (v13)
1. Set `WRO_ACTIVE_TARGET = WRO_TARGET_V13_MAIN` (target 11) → upload `wro_v13_main.cpp`.
2. Open Serial Monitor at 115200.
3. Confirm boot sequence:
   - Banner: `WRO FE 2026 -- Team Faith -- v13.0 main firmware`
   - `Mode: OPEN` or `OBSTACLE` (matches `OBSTACLE_MODE` in `wro_config_v13.h`)
   - `WiFi: OFF, BT: OFF` (Rule 11.10)
   - `AS5600 dual I2C: OK`
   - `VL53L1X FRONT: OK at 0x30`
   - `VL53L1X SIDE: OK at 0x31`
   - `Camera UART2 ready`
   - `ICM-20948 IMU: OK`
   - `Calibrating gyro Z bias...` followed by bias value
   - `System ready. Press E-Stop to start.`
4. Press + release E-Stop. Verify the firmware accepts it as start.
5. While the race runs, hold E-Stop and verify motor stops in <50 ms.

If FAIL → no floor tests; fix the firmware/serial errors first.

### Step D — Actuator sanity
- Steering centered at startup
- Left/right steering direction correct
- Motor direction matches "forward" command
- No motor jitter when target speed = 0

If FAIL → re-check servo center calibration and BTS7960 polarity.

---

## 8) Calibration

### IMU gyro
- Robot still during calibration
- Acceptance: `gyroZbias < 0.05`
- Acceptance: static yaw drift ≤ 2° in 30 s

### Steering center
- Wheels mechanically straight at `SERVO_CENTER_US`
- Adjust horn physically first, then trim software constants
- Acceptance: tracks straight for 1 m without steering trim

### Camera pipeline
- UART v3.0 with 6 fields + XOR checksum
  - `RedX,RedDist,GreenX,GreenDist,ModeFlag,ExtraTag*XX\n`
- Range checks:
  - RedX / GreenX: -160..160
  - RedDist / GreenDist: 0..999

### Odometry
- 3 × 100 cm straight runs
- Acceptance: ≤ 2 cm error on control run

### PID and heading
- Start from v13 defaults (in `wro_config_v13.h`):
  - `PILLAR_KP = 0.45`, `PILLAR_KI = 0.001`, `PILLAR_KD = 0.30`
  - `HEADING_KP = 12.0`, `HEADING_KI = 0`, `HEADING_KD = 2.0`
- Tune Kp first, then Kd, then Ki
- Record every change in `WRO_PID_Tuning_Log.csv`

---

## 9) Runtime health indicators
- Camera timeout warnings
- Encoder loss alarms
- Unexpected lap jumps
- E-Stop release/engage entries
- Oscillating steering (Kp too high)
- Sluggish correction (Kp too low)

---

## 10) Track testing plan (in order)

Run in this sequence (see [`docs/WRO_Track_Test_Cases.md`](WRO_Track_Test_Cases.md)):
1. TC-01 Stand Safety
2. TC-02 E-Stop Reaction
3. TC-03 Camera Timeout Stop
4. TC-04 Encoder Loss Handling
5. TC-05 Lap Counting Stability
6. TC-06 Recovery Behavior
7. TC-07 Start Procedure Compliance
8. TC-08 Finish Behavior Compliance

Record per run: Kp/Kd, battery voltage, floor condition, laps completed, failure mode (if any).

---

## 11) Common failure modes + quick fixes

### Wrong devices on the I2C scan
- Confirm you ran `scan_i2c_v13.cpp` (target 2), not the legacy v11/v12 versions
- `0x70` showing up = stray TCA9548A still wired (shouldn't be in v13)
- Missing `0x29` after boot = VL53L1X XSHUT pin not driven LOW correctly

### IMU/encoder not found
- Verify `0x68` for IMU (AD0 must be GND in v13)
- Verify `0x36` on the correct bus (Left → I2C0, Right → I2C1)
- Check 3.3 V + GND + SDA + SCL with a multimeter
- Reduce bus noise; shorten I2C wires; verify 4.7 kΩ pull-ups present on each bus

### Random camera loss
- Verify OpenMV UART baud (115200) and packet format
- Confirm RX/TX crossed
- Improve cable strain relief and ground

### Encoder dropouts
- Check AS5600 supply (3.3 V) and magnet alignment (1-2 mm gap, centered)
- Check 4.7 kΩ pull-ups on the relevant I2C bus
- Run `test_encoders.cpp` (target 8) to inspect raw data live

### VL53L1X stuck at default `0x29`
- XSHUT pin floating or shorted — verify `vl53l1x_dual.h` boot order
- One sensor's XSHUT released before another's address was written — single-step the boot dance with debug prints

### Robot oscillates
- Lower `PILLAR_KP` / `HEADING_KP`
- Increase damping (`PILLAR_KD` / `HEADING_KD`)
- Reduce max speed (`OBS_MAX_PWM`, `OPEN_MAX_PWM`)

### Heading drift
- Recalibrate gyro on a still surface
- Reduce IMU vibration (foam mount)
- Verify the snap-to-90° works after each corner

Mandatory stop conditions:
- Repeated SAFE_STOP with unknown cause
- Loss of deterministic startup state
- Any uncommanded motor movement

---

## 12) Competition-day Go / No-Go

- One power switch only (Rule 9.10)
- One start button only with a waiting state (Rule 9.11) — same E-Stop button
- No physical mode switches (Rule 9.9) — `OBSTACLE_MODE` is compile-time
- Spare wires / connectors / sensors ready
- Backup flashed ESP32-S3 ready
- Printed wiring map and Quick Race Checklist on hand
- Final firmware version tagged in git
- Battery fully charged and verified
- Tool kit ready (hex keys, screwdrivers, tape, zip ties)
- Last full pre-flight completed and signed

Decision:
- `GO` only if every critical check is PASS
- `NO-GO` if any safety or rule check fails

---

## 13) Sign-off
- Hardware lead: ____________________
- Software lead: ____________________
- Safety lead: ____________________
- Time: ____________________

---

## 14) Suggested next improvements
- Automated preflight script that diffs scanner output against the expected map
- Telemetry CSV export with timestamps for fault post-analysis
- Explicit voltage-sag alarm threshold in firmware and checklist
- Keep `WRO_Rule_Compliance_Matrix.md` and audit docs updated each release

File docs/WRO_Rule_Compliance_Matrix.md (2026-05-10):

# WRO Rule Compliance Matrix

Date: 9 April 2026 (v11-era audit) — **v13 re-audit pending**
Scope: Official WRO 2026 rules + internal project safety rules

> ⚠️ **v13 status (May 2026):** All `src/esp32/eps323.cpp:NNN` line references in this matrix are **stale** — `eps323.cpp` is now `src/esp32/legacy/legacy_eps323.cpp` (v11 reference, inactive). The active firmware is `src/esp32/wro_v13_main.cpp` and its modules `wro_*.{cpp,h}`. The mapping below should be regenerated against the v13 source. Until then, treat status entries as historical.
>
> Rule compliance points that map to v13 modules:
> - **Rule 9.9** (compile-time mode): `src/esp32/wro_config_v13.h` — `#define OBSTACLE_MODE 0/1`
> - **Rule 9.10/9.11** (single start button): `src/esp32/wro_estop.cpp` — press+release start
> - **Rule 9.24.2** (Open finish): `src/esp32/wro_race_fsm.cpp` — `RS_FINISH` after `lap_count >= TARGET_LAPS_RACE`
> - **Rule 9.24.4** (Obstacle finish): `src/esp32/wro_park.cpp` — `PK_FINAL` → `RS_FINISH`
> - **Rule 11.10** (no wireless during runs): `src/esp32/wro_v13_main.cpp` — `WiFi.mode(WIFI_OFF); btStop();` in `setup()`
> - **Internal E-Stop safety**: `src/esp32/wro_estop.cpp` + `src/esp32/wro_race_fsm.cpp` (RS_SAFE_STOP path)

Official source:
- `docs/rules/WRO-2026-Future-Engineers-Self-Driving-Cars-General-Rules.pdf`
- Extracted anchors used in this matrix:
  - Page 17: rules 9.6, 9.9, 9.10, 9.11, 9.13, 9.14
  - Page 19: rules 9.24.2, 9.24.4
  - Page 23: rules 11.1, 11.2

---

## A) Official WRO Rules -> Implementation -> Test
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

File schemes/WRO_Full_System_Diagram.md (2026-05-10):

# WRO Full Structured System Diagram (v13)

> **Active hardware revision:** v13 — ESP32-S3-DevKitC-1 + 2× AS5600 dual-I2C + 2× VL53L1X (XSHUT-based runtime address remap).
> Full pin reference: [`docs/guides/WRO_Wiring_Map_v13.md`](../docs/guides/WRO_Wiring_Map_v13.md).
> Migration notes: [`docs/strategy/WRO_Migration_v12_to_v13.md`](../docs/strategy/WRO_Migration_v12_to_v13.md).

## Modules covered
- Power chain: LiPo 2S/3S, KCD3 main switch, 5 V rail, 3.3 V rail (onboard ESP32-S3 regulator)
- Controllers: ESP32-S3 (motion + sensor fusion), OpenMV H7 Plus (vision)
- Actuators: BTS7960 + brushed DC motor, JX PDI-6221MG steering servo
- Safety / status: E-Stop button, status LED, onboard WS2812 RGB
- I2C0 (Wire, GPIO 8/9): ICM-20948 (0x68) + AS5600 Left (0x36) + VL53L1X Front (0x29 → 0x30)
- I2C1 (Wire1, GPIO 11/12): AS5600 Right (0x36) + VL53L1X Side (0x29 → 0x31)
- VL53L1X XSHUTs on GPIO 15 / 16 (third reserved on GPIO 47)
- UART2: OpenMV camera (115200 baud, ASCII v3 protocol with XOR checksum)
- Grounding: star ground point

```mermaid
flowchart LR
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

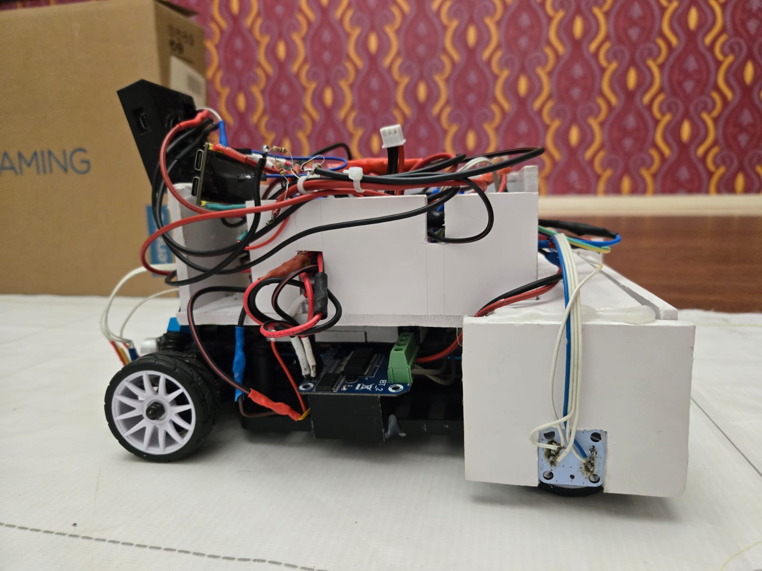
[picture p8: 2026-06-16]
v-photos/left.jpeg

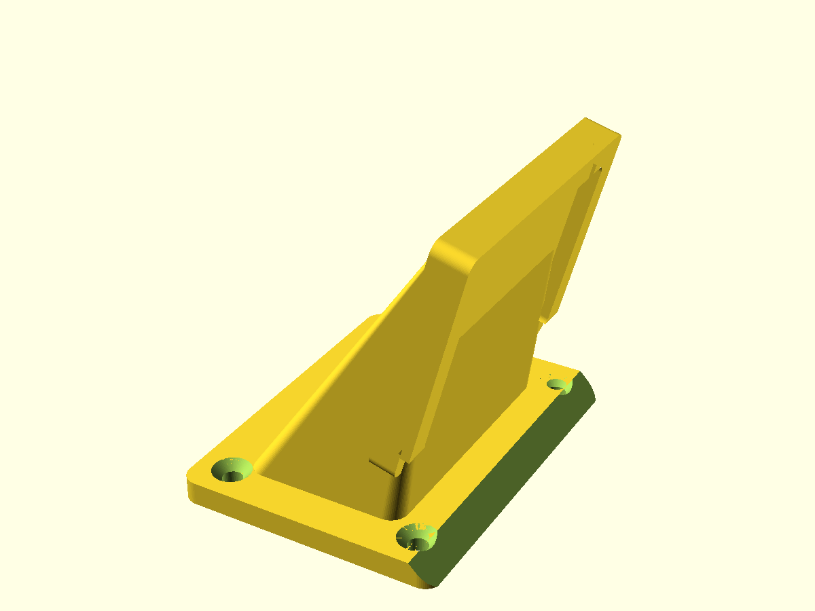
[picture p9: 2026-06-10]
models/OpenMV_H7_mount/openmv_h7_mount.png

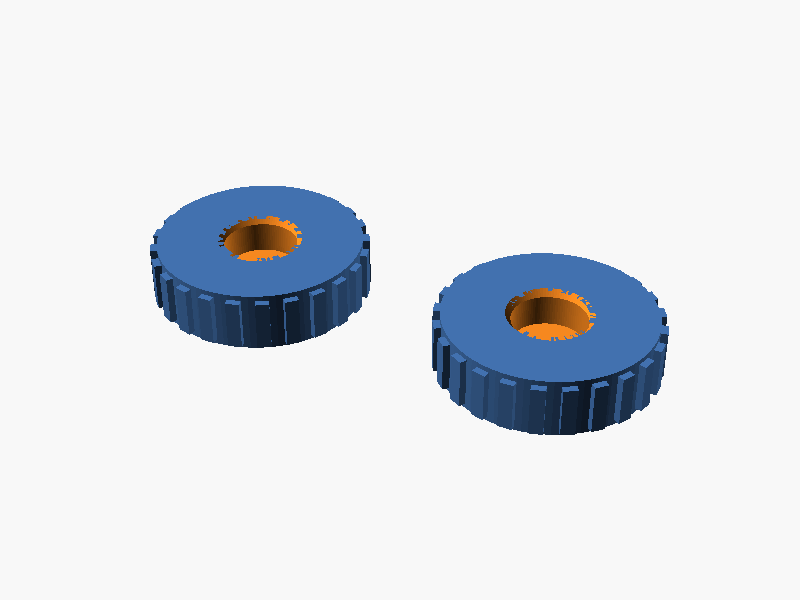
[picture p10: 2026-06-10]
models/AS5600_bracket/magnet_adapter_x2.png

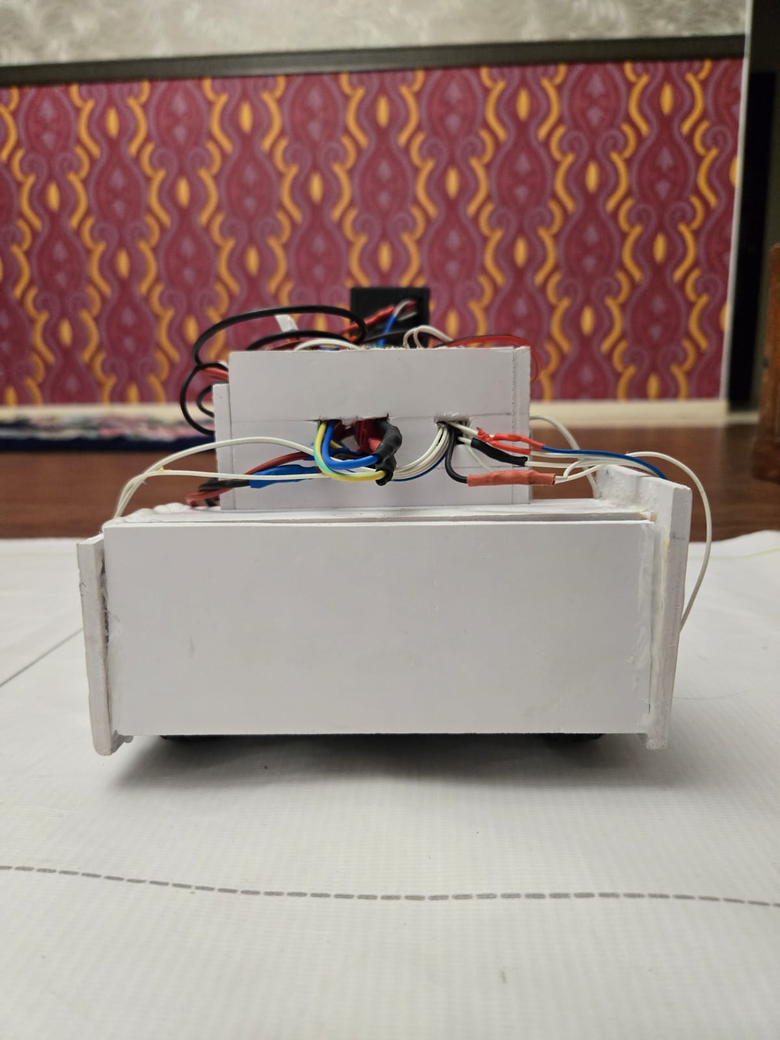
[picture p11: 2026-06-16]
v-photos/back.jpeg

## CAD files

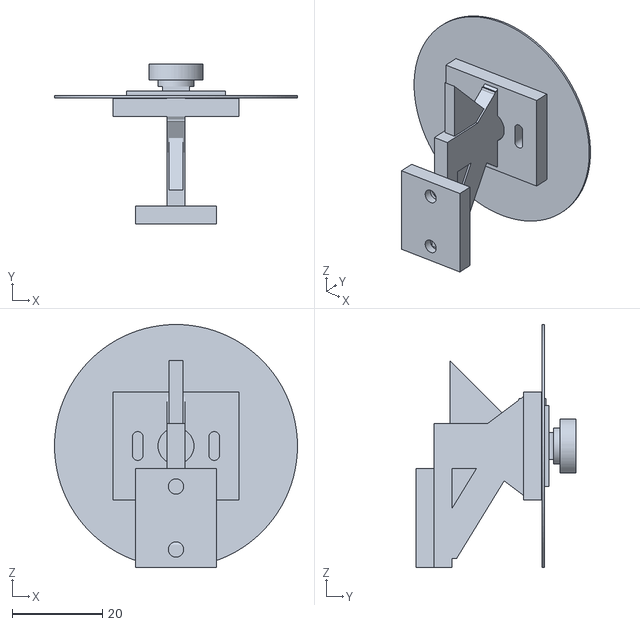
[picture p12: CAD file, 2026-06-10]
models/AS5600_bracket/assembly.stl
54.0 x 35.5 x 54.0

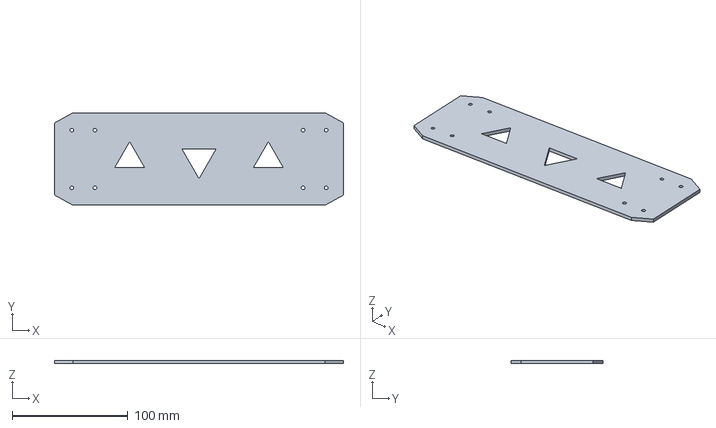
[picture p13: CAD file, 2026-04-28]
models/HSP94182_3D/cad/chassis_plate.step
250.0 x 80.0 x 3.00 mm

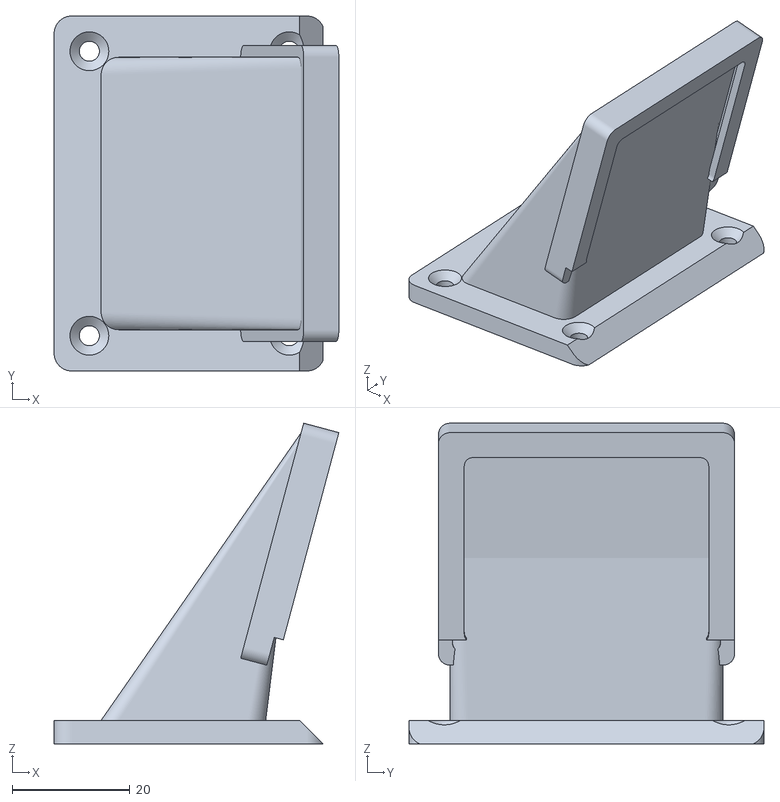
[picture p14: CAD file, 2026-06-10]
models/OpenMV_H7_mount/openmv_h7_mount.stl
48.4 x 60.4 x 54.6

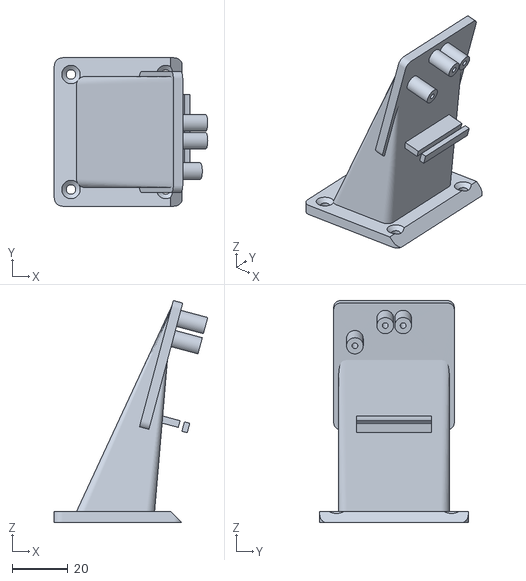
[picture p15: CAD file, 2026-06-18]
models/Pixy2_mount/pixy2_mount.stl
55.0 x 53.2 x 79.6

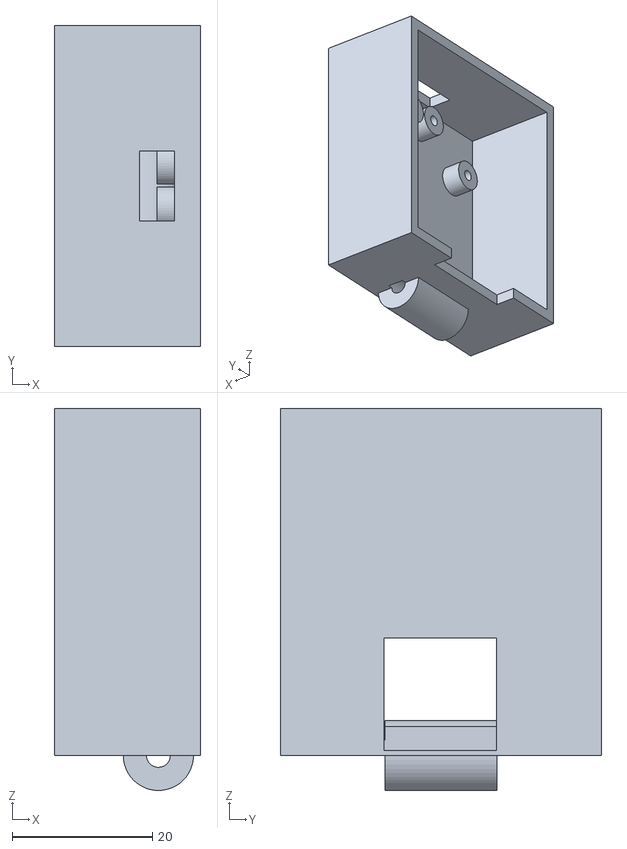
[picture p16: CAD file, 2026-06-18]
models/Pixy2_tilt_cover/cover.stl
20.8 x 45.6 x 54.4

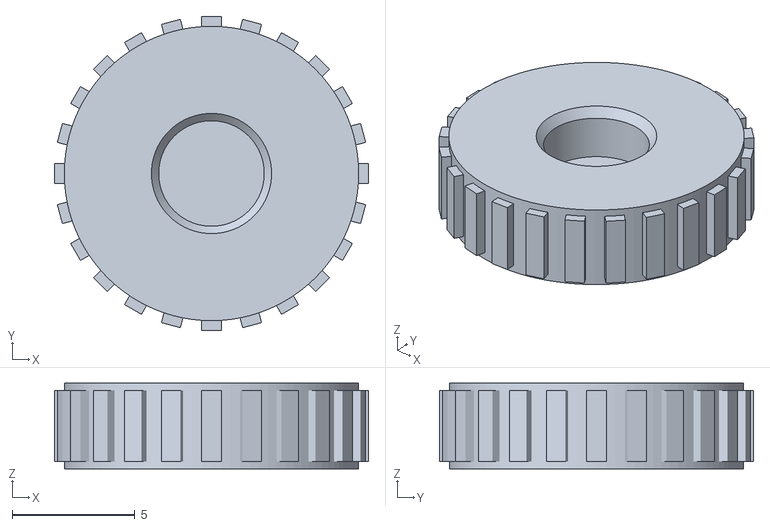
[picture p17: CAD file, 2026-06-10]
models/AS5600_bracket/magnet_adapter.stl
12.8 x 12.8 x 3.50

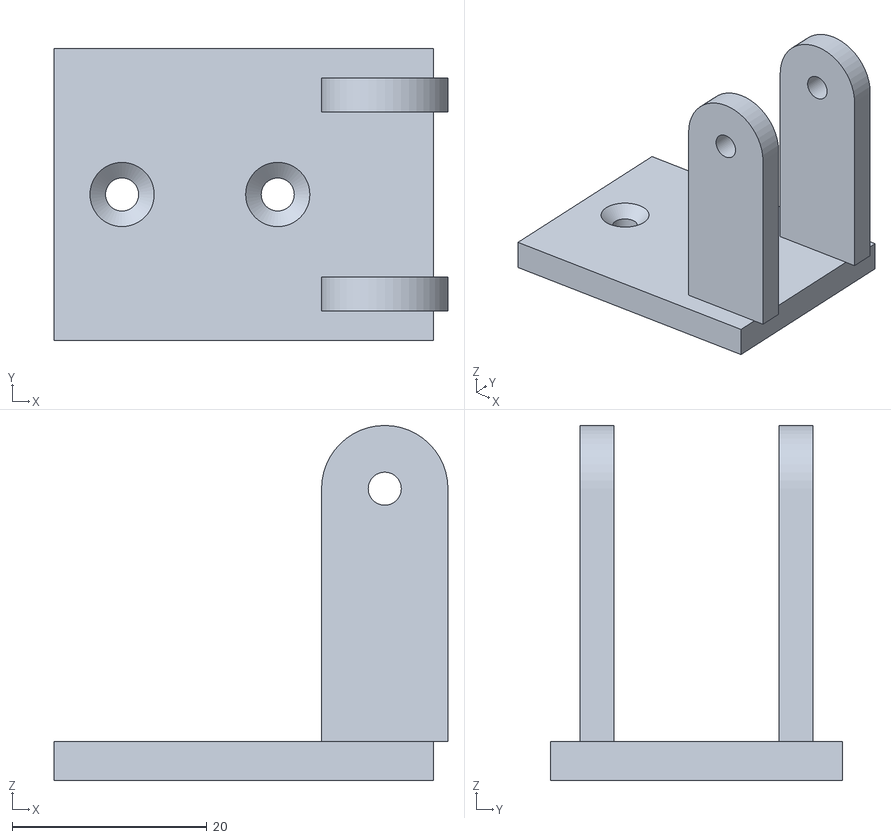
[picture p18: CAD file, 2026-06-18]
models/Pixy2_tilt_cover/bracket.stl
40.5 x 30.0 x 36.5

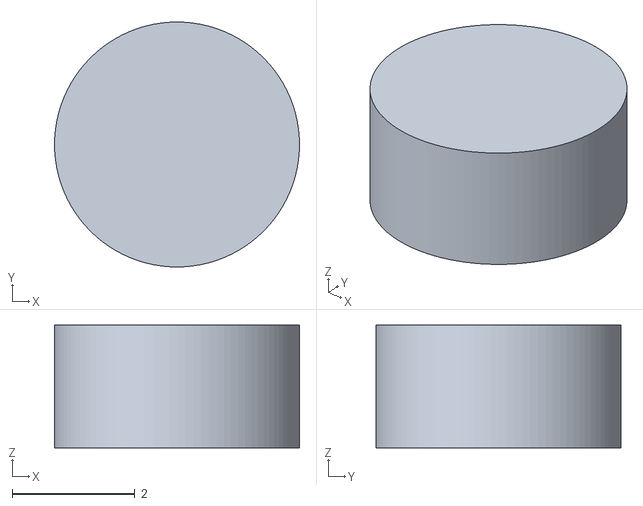
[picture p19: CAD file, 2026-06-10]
models/AS5600_bracket/magnet_dummy.stl
4.00 x 4.00 x 2.00

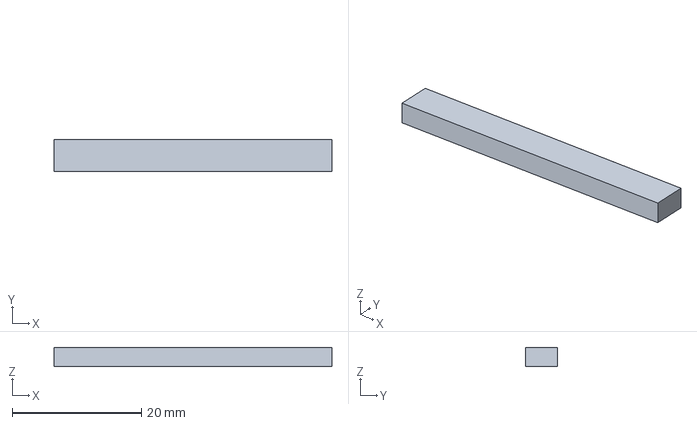
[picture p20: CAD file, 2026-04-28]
models/HSP94182_3D/cad/upper_arm.step
43.0 x 5.00 x 3.00 mm

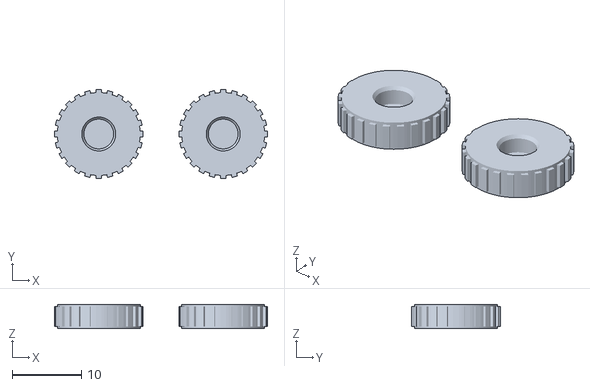
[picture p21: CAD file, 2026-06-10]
models/AS5600_bracket/magnet_adapter_x2.stl
30.8 x 12.8 x 3.50

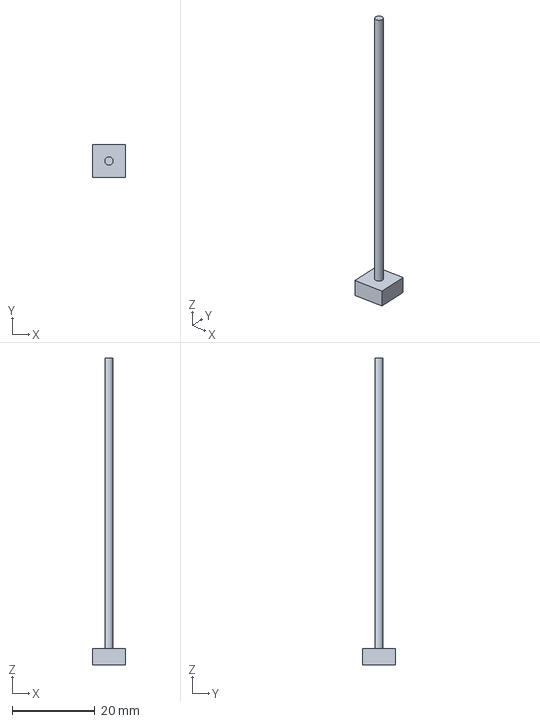
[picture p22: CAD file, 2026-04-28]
models/HSP94182_3D/cad/antenna_mount.step
8.00 x 8.00 x 74.0 mm

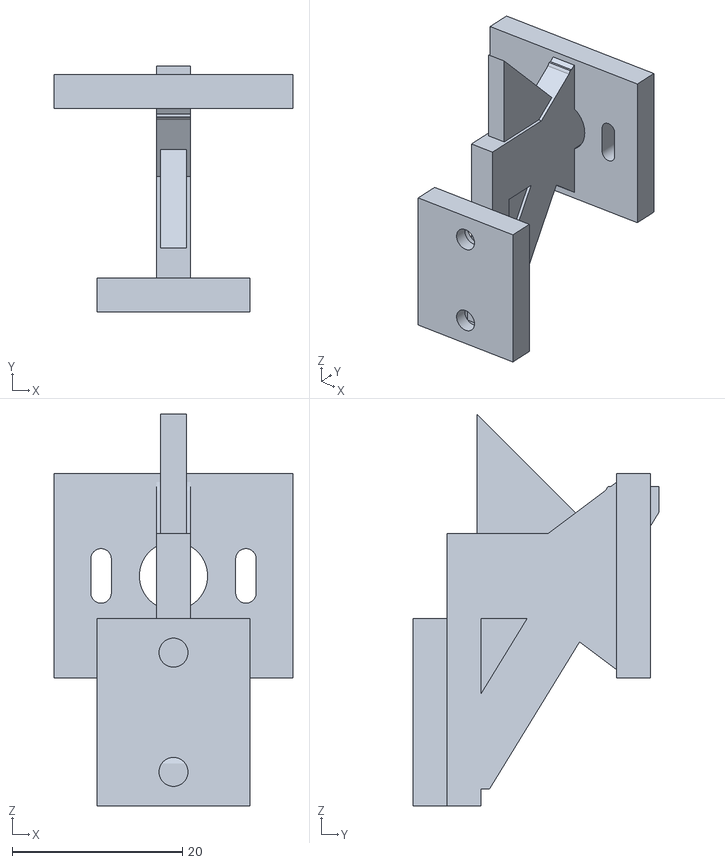
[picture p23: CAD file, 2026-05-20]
models/AS5600_bracket/AS5600_bracket.stl
28.0 x 28.9 x 46.0

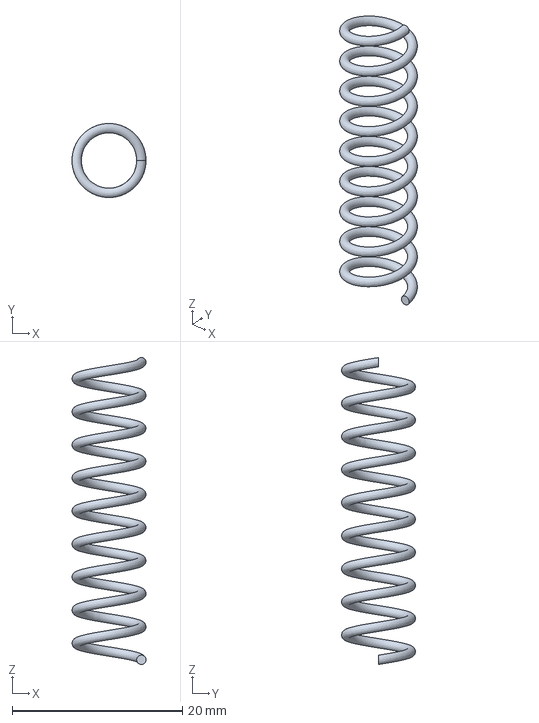
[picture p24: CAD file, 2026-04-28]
models/HSP94182_3D/cad/shock_spring.step
8.70 x 8.70 x 36.1 mm

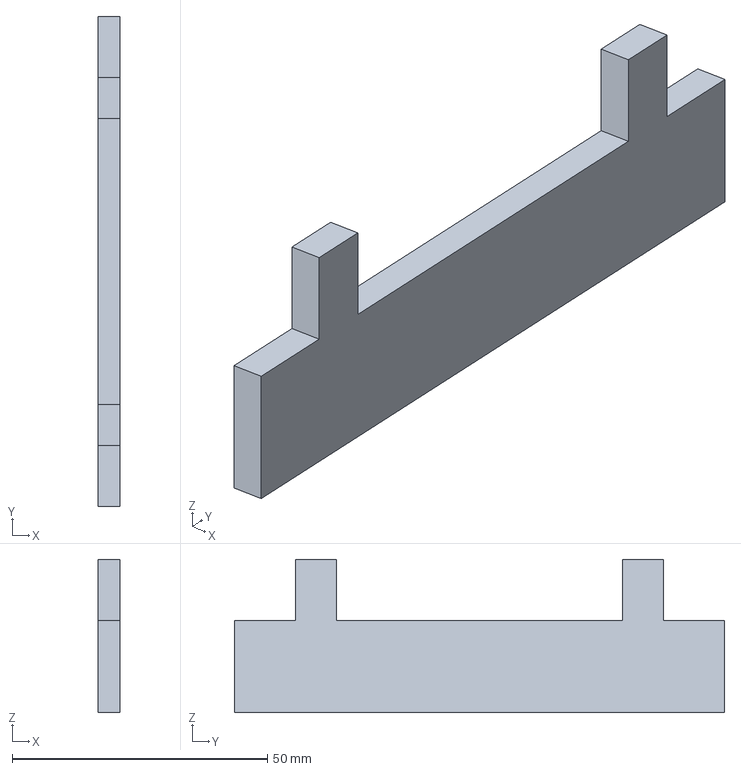
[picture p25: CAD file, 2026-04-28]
models/HSP94182_3D/cad/shock_tower.step
4.40 x 96.0 x 30.0 mm

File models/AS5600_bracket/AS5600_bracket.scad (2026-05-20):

// ============================================================================
//  AS5600 Encoder Bracket — Parametric (v1.0)
//  WRO Future Engineers 2026 • Team Faith
//  Chassis: HSP 94182 (1/16) • Sensor: AS5600 purple breakout (~22x18mm)
//
//  OPEN IN OPENSCAD: https://openscad.org
//  F5 = preview  •  F6 = render  •  File > Export > STL
//
//  PRINT SETTINGS (recommended):
//    Material: PETG (stiffer than PLA, won't creep under vibration)
//    Layer height: 0.2 mm
//    Infill: 60% (rigidity matters more than weight here)
//    Walls: 4 perimeters (kills flex)
//    Print orientation: anchor face flat on bed (strongest layer direction
//    perpendicular to the cantilever bending load)
//    NO supports needed if oriented correctly.
// ============================================================================

/* [Measure these on your robot — units mm] */

// Distance from chassis side face to wheel INNER face
ARM_REACH         = 28;

// Vertical rise from chassis-side anchor to axle (wheel rotation) centerline
ARM_RISE          = 16;

// Air gap nominal (0.5 .. 3.0 — keep around 1.5)
AIR_GAP           = 1.5;

/* [AS5600 purple breakout — verify with calipers] */

// PCB outline
PCB_W             = 22;       // width across the long axis (where holes are)
PCB_H             = 18;       // height (short axis)
PCB_T             = 1.6;      // PCB thickness (clearance pocket only)

// M2 mounting hole spacing on PCB (center-to-center, long axis)
PCB_HOLE_SPACING  = 17;

// AS5600 chip center offset from PCB long-axis center (0 if chip is centered)
CHIP_OFFSET_X     = 0;

// AS5600 chip face height above PCB top (most modules: ~1.0)
CHIP_HEIGHT       = 1.0;

/* [Anchor (chassis-side mounting flange)] */

// Chassis-side anchor: 2 M3 holes vertically stacked
ANCHOR_HOLE_DY    = 14;       // vertical spacing between the two M3 anchor holes
ANCHOR_W          = 18;       // width of anchor flange (along car length)
ANCHOR_H          = 22;       // height of anchor flange (vertical)
ANCHOR_T          = 4;        // anchor flange thickness

/* [Bracket body] */

// Main bracket plate thickness — DO NOT go below 3mm
BRACKET_T         = 4;

// Lateral arm vertical depth (Z height). Bending stiffness ~ depth^3, so
// going from 4mm to 10mm gives ~16x more rigidity. Don't make taller than
// the gap between top deck and suspension top — measure first.
ARM_H             = 10;

// Triangular gusset depth (kills first-mode resonance)
GUSSET_DEPTH      = 14;
GUSSET_T          = 3;

/* [Stability enhancements (v1.1 — convert cantilever into a truss)] */

// Diagonal strut from sensor mount back down to the anchor.
// This is the single biggest rigidity improvement — turns a flexing
// cantilever into a rigid triangle. Enable unless it interferes with
// something on your specific car.
STRUT_ENABLE      = true;
STRUT_W           = 4;        // strut width (X — along car length)
STRUT_T           = 3;        // strut thickness (perpendicular to strut axis)

// Mirror gusset on the OPPOSITE side of the anchor-to-riser corner.
// With gussets on both sides the riser becomes truly rigid in torsion.
DOUBLE_GUSSET     = true;

// Back-buttress on the sensor mount — small horizontal rib that prevents
// the sensor wall from rocking under cable pull or shake.
BACK_BUTTRESS     = true;
BUTTRESS_DEPTH    = 8;

/* [Hole sizes — slight clearance over nominal] */
M2_HOLE           = 2.4;      // tight clearance for M2 screw
M3_HOLE           = 3.4;      // tight clearance for M3 screw
SLOT_RANGE        = 4;        // VERTICAL slot length — lets you slide the PCB
                              // up/down ±2mm to align AS5600 chip with axle
                              // centerline. AIR GAP is tuned separately via
                              // M2 standoff length (see README Step 5c).

/* [Magnet clearance (visual only — not load-bearing)] */
MAGNET_D          = 6.2;      // diametric magnet diameter (with clearance)
MAGNET_T          = 2.6;      // magnet thickness

$fn = 72;

// ============================================================================
//  CALCULATED CONSTANTS
// ============================================================================
// PCB sits parallel to wheel face. AS5600 chip is on the PCB face that points
// toward the wheel. The chip face must be AIR_GAP from the magnet face.
// Bracket "sensor mount" is the wall on the BACK of the PCB.
// Distance from sensor-mount wall to wheel face = AIR_GAP + CHIP_HEIGHT + PCB_T

SENSOR_TO_WALL = AIR_GAP + CHIP_HEIGHT + PCB_T;  // back-of-PCB to wheel face

// ============================================================================
//  ANCHOR FLANGE (vertical plate against chassis side)
// ============================================================================
module anchor_flange() {
    difference() {
        // Body
        translate([-ANCHOR_W/2, 0, -ANCHOR_H/2])
            cube([ANCHOR_W, ANCHOR_T, ANCHOR_H]);

        // Two M3 mounting holes, vertically stacked
        for (dz = [-ANCHOR_HOLE_DY/2, ANCHOR_HOLE_DY/2])
            translate([0, -1, dz])
                rotate([-90, 0, 0])
                cylinder(d=M3_HOLE, h=ANCHOR_T + 2);

        // Counterbore relief (optional — for socket-head M3, depth 2mm)
        for (dz = [-ANCHOR_HOLE_DY/2, ANCHOR_HOLE_DY/2])
            translate([0, ANCHOR_T - 2, dz])
                rotate([-90, 0, 0])
                cylinder(d=6.0, h=2.5);
    }
}

// ============================================================================
//  CANTILEVER ARM — rises from anchor top to axle height, then turns laterally
//  Lateral arm uses ARM_H for vertical depth (bending stiffness scales with
//  depth cubed — 4mm -> 10mm is ~16x stiffer).
// ============================================================================
module cantilever_arm() {
    // Vertical section (anchor top to axle height)
    translate([-BRACKET_T/2, ANCHOR_T, -ANCHOR_H/2])
        cube([BRACKET_T, BRACKET_T, ARM_RISE + ANCHOR_H/2 + ARM_H/2]);

    // Horizontal section (deep section in Z for bending rigidity)
    hull() {
        translate([-BRACKET_T/2, ANCHOR_T, ARM_RISE - ARM_H/2])
            cube([BRACKET_T, BRACKET_T, ARM_H]);
        translate([-BRACKET_T/2, ANCHOR_T + ARM_REACH - SENSOR_TO_WALL - BRACKET_T,
                   ARM_RISE - ARM_H/2])
            cube([BRACKET_T, BRACKET_T, ARM_H]);
    }
}

// ============================================================================
//  GUSSET — triangulated reinforcement between anchor and arm.
//  With DOUBLE_GUSSET=true a mirror copy on the opposite X side makes the
//  riser rigid in torsion (not just bending).
// ============================================================================
// One vertical YZ-plane gusset (triangular fillet) placed at the inside
// corner where the lateral arm meets the riser. Polygon uses
// (-Z_global, Y_global) so rotate([0,90,0]) makes it a vertical plate
// extruded along X.
module gusset_yz(z_corner, y_corner, y_far, z_far, thickness) {
    translate([-thickness/2, 0, 0])
        rotate([0, 90, 0])
        linear_extrude(height = thickness)
        polygon(points=[
            [-z_corner, y_corner],      // right-angle vertex (inside corner)
            [-z_far,    y_corner],      // along riser (vertical leg)
            [-z_corner, y_far]          // along arm (horizontal leg)
        ]);
}

module gusset() {
    // Lower fillet — below the arm, supporting the bottom of the riser-to-arm
    // corner. Right angle at the inside corner (front of riser, bottom of arm).
    riser_front = ANCHOR_T + BRACKET_T - 0.5;       // 0.5mm into riser for merge
    arm_bot     = ARM_RISE - ARM_H/2;
    gusset_yz(
        z_corner = arm_bot,
        y_corner = riser_front,
        y_far    = riser_front + GUSSET_DEPTH,
        z_far    = arm_bot - GUSSET_DEPTH,
        thickness= GUSSET_T
    );

    if (DOUBLE_GUSSET) {
        // Upper fillet — above the arm, mirror of the lower one
        arm_top = ARM_RISE + ARM_H/2;
        gusset_yz(
            z_corner = arm_top,
            y_corner = riser_front,
            y_far    = riser_front + GUSSET_DEPTH,
            z_far    = arm_top + GUSSET_DEPTH,
            thickness= GUSSET_T
        );
    }
}

// ============================================================================
//  SENSOR MOUNT — vertical wall at end of cantilever, holds AS5600 PCB
//  PCB attaches with 2 M2 screws + standoffs.
//  Slots are VERTICAL — they let you align the AS5600 chip with the axle
//  centerline (chip must be centered over the rotating magnet within 0.25mm).
//  Air gap (the perpendicular distance to the magnet) is set by choosing the
//  standoff length between the bracket wall and the PCB.
// ============================================================================
module sensor_mount() {
    mount_x = ANCHOR_T + ARM_REACH - SENSOR_TO_WALL;
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

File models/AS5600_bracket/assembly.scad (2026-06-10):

// ============================================================================
//  AS5600 Encoder Assembly — Bracket + Magnet Adapter
//  WRO Future Engineers 2026 · Team Faith
//
//  This file is a VISUAL ASSEMBLY ONLY. It imports the two real parts —
//    AS5600_bracket.scad   (chassis-side, blue)
//    magnet_adapter.scad   (wheel-side, dark grey)
//  — and places them in the relative position they sit in once installed
//  on the car. The yellow disc between the chip and the magnet is the
//  operating AIR_GAP (1.5 mm). Bracket is stationary; adapter rotates
//  with the wheel.
//
//  DO NOT EXPORT THIS TO STL FOR PRINTING. Export each source file
//  individually for slicing. This file is for sanity-checking alignment
//  in OpenSCAD's preview (F5).
// ============================================================================

use <AS5600_bracket.scad>
use <magnet_adapter.scad>

// ----------------------------------------------------------------------------
//  Constants — kept in sync with the source files. If you change them in
//  the bracket / adapter SCAD, mirror the change here so the assembly stays
//  aligned.
// ----------------------------------------------------------------------------
ANCHOR_T    = 4;     // bracket anchor flange thickness (Y)
ARM_REACH   = 28;    // chassis face -> wheel-side magnet plane (Y)
ARM_RISE    = 16;    // chassis bottom anchor center -> axle centerline (Z)
DISC_T      = 3.5;   // magnet adapter disc thickness
PCB_W       = 22;
PCB_H       = 18;
PCB_T       = 1.6;
CHIP_HEIGHT = 1.0;
AIR_GAP     = 1.5;

// The bracket places the chip face here; the magnet face must sit AIR_GAP
// further out. The original bracket "ghost_magnet" puts the magnet at
// Y = ANCHOR_T + ARM_REACH, so that's also where our real adapter must
// project its magnet pocket opening.
MAGNET_FACE_Y = ANCHOR_T + ARM_REACH;                          // = 32
SENSOR_TO_WALL = AIR_GAP + CHIP_HEIGHT + PCB_T;                // = 4.1
SENSOR_WALL_Y  = ANCHOR_T + ARM_REACH - SENSOR_TO_WALL;        // PCB back face
CHIP_FACE_Y    = SENSOR_WALL_Y + PCB_T + CHIP_HEIGHT;          // = 30.5

// ----------------------------------------------------------------------------
//  1) Bracket — at origin, chassis-side
// ----------------------------------------------------------------------------
bracket();

// ----------------------------------------------------------------------------
//  2) Magnet adapter — wheel-side, mounted on the rotation axis.
//
//  Adapter native frame:
//      disc lies on the XY plane (Z = 0 .. DISC_T)
//      magnet pocket opens toward +Z
//      magnet axis = Z axis
//
//  We need:
//      magnet axis  -> bracket Y axis (along chassis-to-wheel direction)
//      pocket opens toward -Y (back toward the AS5600 chip)
//      pocket face at Y = MAGNET_FACE_Y
//      axis crosses (X=0, Z=ARM_RISE)
//
//  rotate([90,0,0]) maps +Z -> -Y. After that, the pocket opening sits at
//  Y = -DISC_T, so we translate by (0, MAGNET_FACE_Y + DISC_T, ARM_RISE).
// ----------------------------------------------------------------------------
color([0.35, 0.35, 0.35])
    translate([0, MAGNET_FACE_Y + DISC_T, ARM_RISE])
    rotate([90, 0, 0])
    adapter();

// ----------------------------------------------------------------------------
//  3) Reference geometry (visual context only — not part of either print)
// ----------------------------------------------------------------------------

// PCB — sits on the front face of the sensor mount wall
color([0.45, 0.25, 0.5, 0.55])
    translate([-PCB_W/2, SENSOR_WALL_Y, ARM_RISE - PCB_H/2])
    cube([PCB_W, PCB_T, PCB_H]);

// AS5600 chip — sits on the wheel-facing side of the PCB
color([0.1, 0.1, 0.1, 0.9])
    translate([-3, SENSOR_WALL_Y + PCB_T, ARM_RISE - 3])
    cube([6, CHIP_HEIGHT, 6]);

// Air gap (yellow translucent disc) — what the encoder actually reads through
color([1.0, 0.85, 0.1, 0.45])
    translate([0, CHIP_FACE_Y, ARM_RISE])
    rotate([-90, 0, 0])
    cylinder(d=8, h=AIR_GAP, $fn=72);

// Wheel inner-face plane (transparent grey) — where the adapter glues on.
// NOTE: bracket places the magnet 4 mm beyond ARM_REACH, so on a real HSP
// 94182 wheel the adapter must sit inside a hub recess OR be glued onto a
// hub feature that protrudes ~4 mm past the inner face. Verify with calipers.
color([0.5, 0.5, 0.5, 0.15])
    translate([0, ARM_REACH, ARM_RISE])
    rotate([-90, 0, 0])
    cylinder(d=54, h=0.5, $fn=96);   // WHEEL_D = 54 mm (chassis.scad)

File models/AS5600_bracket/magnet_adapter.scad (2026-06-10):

// ============================================================================
//  Magnet Centering Adapter — Parametric (v1.0)
//  WRO Future Engineers 2026 • Team Faith
//
//  Problem: A magnet glued straight to a wheel face drifts off-center as the
//  glue creeps under vibration. If the magnet is off-center by >0.25mm, the
//  AS5600 reports non-linear angle (wobble in serial output during slow spin).
//
//  Solution: A small printed disc with a precision pocket for the magnet.
//  Glue the disc to the wheel center (or hex-hub end). Pocket walls keep
//  the magnet concentric forever.
//
//  PRINT SETTINGS:
//    Material: PETG or PLA (low load on this part)
//    Layer height: 0.12 mm (matters here — pocket must be precise)
//    Infill: 100% (small part, give it strength)
//    No supports.
//    Print 2 (one for each wheel).
// ============================================================================

/* [Diametric magnet — measure yours] */
MAGNET_D       = 4.0;   // our magnet: 4mm cylindrical diametric (datasheet nominal is 6mm)
MAGNET_T       = 2.0;   // magnet thickness
MAGNET_FIT     = 0.30;  // clearance added (0.10 = tight, 0.20 = loose-glue, 0.30 = drop-in for glue)

/* [Adapter disc] */
DISC_OD        = 12.0;  // overall outer diameter — fits over wheel center
DISC_T         = 3.5;   // total disc thickness
POCKET_DEPTH   = MAGNET_T + 0.2;  // pocket holds magnet flush + a touch deep

/* [Centering pilot (optional)] */
// If your HSP wheel has a 5mm hex hole or center pin, set this to 5.1 for a
// snug slip-fit that centers the adapter on the rotation axis automatically.
// Set to 0 to disable (flat-bottom adapter, glue-only).
PILOT_D        = 0;     // 5.1 for HSP 94182 hex-hub centering, 0 for glue-only
PILOT_DEPTH    = 2.0;

/* [Knurled grip ring (optional — improves glue bond surface area)] */
KNURL          = true;
KNURL_TEETH    = 24;
KNURL_DEPTH    = 0.4;

$fn = 96;

// ============================================================================
//  MAIN BODY
// ============================================================================
module adapter() {
    difference() {
        // Outer disc
        union() {
            cylinder(d=DISC_OD, h=DISC_T);
            if (KNURL) knurl_ring();
        }

        // Magnet pocket (top face)
        translate([0, 0, DISC_T - POCKET_DEPTH])
            cylinder(d=MAGNET_D + MAGNET_FIT, h=POCKET_DEPTH + 0.1);

        // Optional pilot hole (bottom face) for centering on hex hub
        if (PILOT_D > 0)
            translate([0, 0, -0.1])
                cylinder(d=PILOT_D, h=PILOT_DEPTH + 0.1);

        // Tiny chamfer on pocket entry — helps magnet drop in
        translate([0, 0, DISC_T - 0.4])
            cylinder(d1=MAGNET_D + MAGNET_FIT, d2=MAGNET_D + MAGNET_FIT + 0.6, h=0.4);
    }
}

module knurl_ring() {
    // Grip ridges must STRADDLE the disc OD: embedded ~0.6 mm into the body so
    // the union is a solid overlap (watertight), and protruding KNURL_DEPTH past
    // the OD as the actual grip texture. Teeth that merely touch the OD tangent
    // produce zero-width slivers → non-manifold edges that some slicers choke on.
    embed = 0.6;                                    // solid overlap into the disc
    width = embed + KNURL_DEPTH;                     // total radial extent of tooth
    cx    = DISC_OD/2 - embed/2 + KNURL_DEPTH/2;     // peak lands at OD/2 + KNURL_DEPTH
    for (i = [0:KNURL_TEETH-1]) {
        angle = i * 360 / KNURL_TEETH;
        rotate([0, 0, angle])
            translate([cx, 0, DISC_T/2])
            cube([width, 0.8, DISC_T - 0.6], center=true);
    }
}

// ============================================================================
//  PREVIEW with ghost magnet
// ============================================================================
SHOW_MAGNET = true;

module ghost_magnet() {
    color([0.6, 0.2, 0.2, 0.7])
        translate([0, 0, DISC_T - MAGNET_T])
        cylinder(d=MAGNET_D, h=MAGNET_T);
    // North/south marker (visual reminder — diametric, not axial)
    color([0.9, 0.9, 0.9])
        translate([0, 0, DISC_T - MAGNET_T/2])
        cube([MAGNET_D + 0.5, 0.3, 0.1], center=true);
}

// ============================================================================
adapter();
// $preview is true in F5/PNG preview, false during F6/STL render — so the ghost
// magnet is shown for visualization but NEVER baked into the exported STL.
if (SHOW_MAGNET && $preview) ghost_magnet();

// ============================================================================
//  USAGE
//  1. Print 2 adapters (one per rear wheel).
//  2. Drop magnet into pocket — should be snug. If too tight, reprint with
//     MAGNET_FIT = 0.20. If too loose, MAGNET_FIT = 0.10.
//  3. Verify magnet is DIAMETRICALLY magnetized: a steel paperclip should
//     attract to the SIDE of the magnet (not the face). If it attracts to
//     the face, you have an axial magnet — wrong type — replace it.
//  4. Glue adapter to wheel hub center with cyanoacrylate (super glue).
//     Press for 30 sec, cure 1 hour before driving.
//  5. With wheel mounted, spin by hand and watch AS5600 raw angle on serial:
//     should sweep 0..4095 smoothly. If it wobbles back-and-forth around
//     the true rotation, adapter is off-center — peel off and redo.
// ============================================================================

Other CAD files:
models/HSP94182_3D/cad/steering_hub.step
models/HSP94182_3D/cad/upper_deck.step
models/HSP94182_3D/cad/driveshaft.step
models/HSP94182_3D/cad/body_post.step
models/AS5600_bracket/magnet_adapter_x2.scad
models/AS5600_bracket/magnet_dummy.scad
models/HSP94182_3D/cad/HSP94182_assembly.step
models/HSP94182_3D/cad/lower_arm.step
models/HSP94182_3D/cad/shock_body.step
models/HSP94182_3D/chassis.scad
models/OpenMV_H7_mount/assembly.scad
models/OpenMV_H7_mount/openmv_h7_mount.scad
models/Pixy2_mount/pixy2_mount.scad
models/Pixy2_tilt_cover/pixy2_tilt_cover.scad

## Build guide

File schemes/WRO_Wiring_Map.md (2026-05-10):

# WRO Wiring Map (v13)

> **Active hardware revision:** v13 (ESP32-S3 + 2× AS5600 dual-I2C + 2× VL53L1X XSHUT-remap).
> The full pin reference is at [`docs/guides/WRO_Wiring_Map_v13.md`](../docs/guides/WRO_Wiring_Map_v13.md);
> this file is the short summary for at-a-glance lookup.

## ESP32-S3-DevKitC-1 (N8R8) Pin Map

### I2C0 — Wire (3 devices)
- GPIO 8  → SDA (ICM-20948 0x68 + AS5600 Left 0x36 + VL53L1X Front 0x30 post-remap)
- GPIO 9  → SCL (same)

### I2C1 — Wire1 (2 devices)
- GPIO 11 → SDA (AS5600 Right 0x36 + VL53L1X Side 0x31 post-remap)
- GPIO 12 → SCL (same)

### VL53L1X XSHUT pins
- GPIO 15 → VL53L1X Front XSHUT (I2C0)
- GPIO 16 → VL53L1X Side XSHUT (I2C1)
- GPIO 47 → reserved for an optional 3rd VL53L1X (I2C0)

### UART2 — OpenMV H7 Plus camera
- GPIO 17 → RX (from OpenMV TX)
- GPIO 18 → TX (to OpenMV RX)

### BTS7960 motor driver
- GPIO 38 → R_EN
- GPIO 39 → L_EN
- GPIO 40 → R_PWM (forward, LEDC Ch0)
- GPIO 41 → L_PWM (reverse, LEDC Ch1)

### Steering servo
- GPIO 42 → JX PDI-6221MG PWM

### Control I/O
- GPIO 21 → E-Stop button (INPUT_PULLUP, active LOW)
- GPIO 2  → Status LED
- GPIO 48 → RGB LED (WS2812 onboard DevKit)

## Power Rails
- **5V rail:** ESP32-S3 VIN, OpenMV, JX servo, VL53L1X VIN (sensors include onboard 2.8 V LDO)
- **3.3V rail:** ICM-20948, AS5600 × 2 (from ESP32-S3 onboard regulator)
- **Motor power:** LiPo 2S/3S → BTS7960 directly
- **Common GND** across all components is mandatory

## Notes
- Add external 4.7 kΩ pull-ups on each I2C bus (most breakouts already include them; verify with a meter).
- VL53L1X address-remap dance (in `vl53l1x_dual.h`): hold every XSHUT low at boot, bring sensors up one at a time, write each to a unique runtime address.
- Servo: re-measure lock-to-lock µs on the actual chassis (target 7 firmware) and add a 60 µs margin from each end-stop to avoid stall-brownout.

## What changed across revisions
| Component | v11 | v12 (planned) | v13 (current) |
|---|-----|---|---|
| MCU | ESP32 DevKitC V4 | ESP32-S3-DevKitC-1 N8R8 | ESP32-S3-DevKitC-1 N8R8 |
| Encoders | 2× AS5600 (I2C, mux) | 2× AS5048A (SPI) | 2× AS5600 (dual native I2C) |
| Distance | VL53L1X (mux) | TFMini-S (UART, 12 m) | VL53L1X (XSHUT remap) |
| I2C mux | TCA9548A (0x70) | None | None — replaced by topology |
| I2C buses | 1 (with mux) | 1 | 2 (Wire + Wire1) |
| Odometry | 277 ticks/cm | 1110 ticks/cm | 277 ticks/cm |

For the migration step-by-step, see [`docs/strategy/WRO_Migration_v12_to_v13.md`](../docs/strategy/WRO_Migration_v12_to_v13.md).

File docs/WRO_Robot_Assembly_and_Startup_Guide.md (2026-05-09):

# 🔧 WRO Future Engineers — Full Robot Assembly Guide

> **Team Faith | v13 Hardware (May 2026)**
>
> This document covers building the robot **from unboxing to first run**. Every step has verification points (✅), photo cues 📸, and time estimates ⏱️. **Don't move on until the current step passes.**
>
> **v13 hardware (May 2026):** ESP32-S3-DevKitC-1 N8R8 main board + 2× AS5600 encoders on dual native I2C + 2× VL53L1X distance sensors with XSHUT-based runtime address remapping + ICM-20948 IMU + OpenMV H7 Plus camera + BTS7960 motor driver + JX PDI-6221MG servo. **No TCA9548A I2C multiplexer.** Authoritative references for v13:
> - Pin map: [`docs/WRO_Wiring_Map_v13.md`](WRO_Wiring_Map_v13.md)
> - v12 → v13 migration: [`docs/WRO_Migration_v12_to_v13.md`](WRO_Migration_v12_to_v13.md)
> - Active firmware: `src/esp32/wro_v13_main.cpp` (target 11)
> - I2C scanner: `src/esp32/scan_i2c_v13.cpp` (target 2, scans both buses)

---

## Stage navigation

| # | Stage | Difficulty | ⏱️ Time |
|:-:|---|:---:|:---:|
| 1 | [Chassis prep](#stage-1-chassis-prep) | 🟢 | 2h |
| 2 | [Power chain](#stage-2-power-chain) | 🟡 | 3-4h |
| 3 | [Motor and BTS7960 driver](#stage-3-motor-and-bts7960-driver) | 🟢 | 1-2h |
| 4 | [Steering servo](#stage-4-steering-servo) | 🟢 | 1h |
| 5 | [ESP32-S3 main board](#stage-5-esp32-s3-main-board) | 🟢 | 1h |
| 6 | [Dual I2C buses](#stage-6-dual-i2c-buses) | 🟡 | 2h |
| 7 | [AS5600 encoders](#stage-7-as5600-encoders) | 🔴 | 3-4h |
| 8 | [IMU (ICM-20948)](#stage-8-imu-icm-20948) | 🟡 | 2h |
| 9 | [OpenMV H7 Plus camera](#stage-9-openmv-h7-plus-camera) | 🟡 | 2h |
| 10 | [VL53L1X ToF sensors](#stage-10-vl53l1x-tof-sensors) | 🟡 | 2h |
| 11 | [E-Stop button](#stage-11-e-stop-button) | 🟢 | 30m |
| 12 | [Status LED](#stage-12-status-led) | 🟢 | 15m |
| 13 | [Final wire dressing](#stage-13-final-wire-dressing) | 🟡 | 2-3h |
| 14 | [Firmware flashing](#stage-14-firmware-flashing) | 🟡 | 2h |
| 15 | [Calibration and first run](#stage-15-calibration-and-first-run) | 🔴 | 4-6h |

---

## Tools and consumables

### Required tools

| Tool | Purpose |
|---|---|
| 25-40 W soldering iron + Sn60/Pb40 | Connectors, caps, resistors |
| Phillips PH1/PH2 screwdriver | HSP chassis, sensor mounts |
| Hex keys 1.5/2/2.5 mm | HSP chassis, pinion, encoders |
| Digital multimeter | Voltage, continuity, short-circuit checks — **every stage** |
| Caliper (0.1 mm resolution) | Wheel diameter for odometry |
| Wire cutters + stripper | Wires |
| Heat gun (or lighter) | Heat-shrink tubing |
| Anti-static tweezers | SMD parts, AS5600 magnets |

### Consumables

- Heat-shrink tubing assortment (3 / 5 / 8 mm)
- Sn60/Pb40 1 mm solder, ~1 m
- Flux (rosin or LTI-120), 1 unit
- Cable ties 100 mm — 30+
- Double-sided 3M VHB tape
- Dupont male/female jumpers — 40
- Insulating tape (emergency)
- Super glue (AS5600 magnet fixation)
- Hot glue, 3-4 sticks
- 3 mm foam, 5×5 cm (IMU vibration isolation)

---

## BOM check before you start

> ⚠️ **STOP** — verify every component before you start. Realizing a part is missing on stage 10 burns a whole day.

### Mechanics
- [ ] HSP 94182 1/16 4WD chassis (assembled: wheels + suspension + 380 motor)
- [ ] 16T M0.6 pinion, Ø2.3 mm bore (verify pitch — if stock is M0.48, source M0.6)
- [ ] JX PDI-6221MG servo (with included horns)

### Electronics — controllers
- [ ] **ESP32-S3-DevKitC-1 N8R8** (USB-C, native USB-OTG, all-bidirectional GPIOs)
- [ ] OpenMV Cam H7 Plus (with camera module + USB cable)

### Electronics — sensors and drivers
- [ ] BTS7960 43A motor driver (8-pin connector)
- [ ] GY-ICM20948V2 IMU (verify silkscreen says **ICM-20948**, not MPU-6050)
- [ ] AS5600 magnetic encoder × 2 (each kit includes a Ø6 mm diametrically magnetized magnet)
- [ ] VL53L1X ToF × 2 (Pololu or Adafruit breakout)

### Power
- [ ] Li-ion / LiPo 7.4 V 2000 mAh, T-plug (charged!)
- [ ] LM2596 DC-DC step-down × 2
- [ ] T-plug → XT60 adapter + spare XT60 pair
- [ ] KCD3 toggle switch × 1 (only one — WRO Rule 9.10)
- [ ] 0.1 µF ceramic caps (104) × 10
- [ ] 4.7 kΩ resistors × 4 (I2C pull-ups, two per bus)
- [ ] 220 Ω resistor × 1 (LED)
- [ ] 10 kΩ resistor × 1 (E-Stop pull-up, optional — internal pull-up usually sufficient)

---

## Stage 1: Chassis prep

> ⏱️ ~2 hours | 🟢 Easy

### 1.1. Strip the unwanted parts

The HSP 94182 ships with a stock receiver, ESC, and shell — all of these come off:

1. Pop the body shell off (4 corner clips, pull up).
2. Locate and unplug the stock ESC (3 wires to the motor + 2 power leads).
3. Unplug the stock receiver (servo connector to ESC).
4. **Carefully** remove both modules.
5. Keep on the chassis: suspension, 380 motor, servo bracket, wheels, drive shafts.

> ⛔ **Do NOT remove** the steering rods or suspension arms. Their geometry is set at the factory; reassembling without photos costs 2 hours.

📸 *Photograph the chassis before and after stripping — useful for the `v-photos/` folder.*

### 1.2. Pinion swap (if needed)

Verify the stock pinion pitch. If it's M0.48 or M0.5, swap to M0.6:

1. Loosen the pinion grub screw (1.5 mm hex).
2. Pull the pinion off the motor shaft. If it sticks, heat with a hot-air gun for 10 s (50-60 °C) and try again, or use a small puller.
3. Slide the **16T M0.6 Ø2.3 mm** pinion onto the shaft.
4. Tighten the grub screw onto the **flat** of the shaft.
5. **Backlash check:** slip a sheet of paper between pinion and spur, rotate, and pull the paper out. Aim for ~0.1 mm.

| Symptom | Cause | Fix |
|---|---|-----|
| Gears whining | Backlash too tight | Move motor 0.1 mm out |
| Gears clicking | Backlash too loose | Move motor in |
| Vibration at high RPM | Grub screw not on the flat | Reposition on the flat |

### 1.3. Mount the JX PDI-6221MG servo

1. Insert the servo into the HSP servo bay (rectangular cutout).
2. Secure with 4 screws from the servo's kit (use included rubber grommets if any).
3. **Servo horn — critical:** with **power off**, manually rotate the servo to its mechanical center, then fit the horn so the front wheels point straight, and tighten the center screw.
4. Connect the steering tie rod to the horn.

### 1.4. Wheel diameter for odometry

This is **critical** for accurate distance counting:

1. Remove one wheel.
2. Caliper the **outer** diameter of the tire (squeeze lightly to simulate load).
3. Record: **D = ___ mm**.
4. Compute ticks/cm:
```
Circumference C = π × D mm
TICKS_PER_CM = 4096 / (C / 10)

Example: D = 47 mm -> C = 147.7 mm -> 4096 / 14.77 ≈ 277 ticks/cm
```
5. Update `TICKS_PER_CM` in `src/esp32/wro_hw_config_v13.h` if your wheels differ from the default 47 mm.

✅ **Stage 1 checklist:**
- [ ] Chassis is clean — ESC, receiver, body removed
- [ ] Pinion installed; gears are quiet
- [ ] Servo installed; horn at mechanical center; wheels straight
- [ ] Wheel diameter measured: D = ___ mm, TICKS_PER_CM = ___
- [ ] 📸 Clean-chassis photo taken

---

## Stage 2: Power chain

> ⏱️ 3-4 hours | 🟡 Medium difficulty
>
> ⛔ **Polarity!** Reversing + and − on the LiPo = **instant** electronics meltdown. Verify every wire with a multimeter **before** plugging it in.

### 2.1. Power architecture (WRO 2026 compliant)

> **WRO Rule 9.10:** "Only ONE switch is allowed to power on the vehicle."

```
LiPo 7.4V ──T-plug──> T->XT60 adapter ──> XT60
                                          │
                                  KCD3 (the only switch)
                                          │
                            ┌─────────────┼─────────────┐
                            │             │             │
                            v             v             v
                      BTS7960 (VCC)   LM2596 #1     LM2596 #2
                      7.4V direct    -> 5.00V       -> 3.30V
                      (motor)       (ESP32, servo)  (sensors)
```

**Loads per rail:**

| Rail | Voltage | Loads | Peak current |
|---|:---:|---|:---:|
| **Motor** | 7.4 V | BTS7960 → 380 motor | ~8 A peak |
| **5 V** | 5.00 V | ESP32-S3 VIN, JX servo, OpenMV VIN, VL53L1X VIN | ~3 A |
| **3.3 V** | 3.30 V | ICM-20948, AS5600 ×2 | ~0.2 A |

> Note: ESP32-S3 has its own onboard 3.3 V regulator — it powers the I2C-bus pull-ups and the AS5600s directly from the 3.3 V pin. The external LM2596 #2 is mostly redundant in v13; you can omit it if the breakout boards have onboard LDOs.

### 2.2. Set up LM2596 BEFORE plugging in any electronics

> ⛔ Set the voltage **first**, then connect the load. If LM2596 is at 12 V from the factory, the ESP32 dies.

**LM2596 #1 → 5 V:**
1. Connect IN+ / IN− to the battery via temporary alligator clips.
2. Power on.
3. Multimeter on OUT+/OUT−.
4. Slowly turn the trim pot until it reads **5.00 V ± 0.05 V**.
5. Verify under load: 100 Ω resistor (50 mA) — voltage should not sag.
6. Power off, mark the regulator with "5V".

**LM2596 #2 → 3.3 V** (optional with onboard breakout LDOs):
1. Same procedure, target **3.30 V ± 0.05 V**.
2. Mark "3.3V".

### 2.3. Solder the power wiring

1. Cut 14 AWG: red 30 cm + black 30 cm.
2. Strip 5 mm on every end.
3. Solder XT60 to the wires from the battery (red → +, black → −).
4. From the XT60 **red (+)**, run through KCD3 and split into 3:
   - → BTS7960 B+ (14 AWG, motor current!)
   - → LM2596 #1 IN+ (22 AWG OK)
   - → LM2596 #2 IN+ (22 AWG OK, if used)
5. **Black (−)** from XT60 splits into 3:
   - → BTS7960 B−
   - → LM2596 #1 IN−
   - → LM2596 #2 IN−
6. Heat-shrink every joint (5 mm).

### 2.4. Motor EMI filtering

> The 380 motor produces strong EMI. Without filtering, I2C hangs, UART drops frames, the IMU drifts.

**3× 0.1 µF ceramic caps on the motor:**
```
        0.1µF
  (+)────┤├────(−)        between motor terminals
  (+)────┤├────(case)      + to motor case
  (−)────┤├────(case)      − to motor case
```

Plus:
- 0.1 µF on BTS7960 VCC-GND (right at the board)
- 0.1 µF on LM2596 #1 OUT-GND
- 0.1 µF on LM2596 #2 OUT-GND (if used)
- **470 µF electrolytic** on the 5 V rail (catches motor-start sag)

### 2.5. Verify with a multimeter (KCD3 ON)

| # | Test | Expected | If wrong |
|:-:|---|:---:|---|
| 1 | LM2596 #1 OUT | 5.00 V ±0.05 | Re-trim |
| 2 | LM2596 #2 OUT | 3.30 V ±0.05 | Re-trim |
| 3 | Short test 7.4 V+ ↔ GND | open (∞) | ⛔ Find and remove the short |
| 4 | Short test 5 V+ ↔ GND | open | ⛔ |
| 5 | Short test 3.3 V+ ↔ GND | open | ⛔ |
| 6 | KCD3 OFF → battery V | 0 V on every rail | Switch is bad |

✅ **Stage 2 checklist:**
- [ ] LM2596 #1: 5.00 V ± 0.05 V (marked)
- [ ] LM2596 #2: 3.30 V ± 0.05 V (marked) or omitted with onboard LDOs
- [ ] KCD3 is the only switch and gates everything
- [ ] Caps installed: 3 on the motor + 1 on BTS7960 + 1 per LM2596 + 1× 470 µF electrolytic on 5 V
- [ ] All joints heat-shrunk
- [ ] No shorts — multimeter confirms
- [ ] 📸 Power harness photo

---

## Stage 3: Motor and BTS7960 driver

> ⏱️ 1-2 hours | 🟢 Easy

### 3.1. BTS7960 wiring (v13 pin map)

| BTS7960 pin | Goes to | Wire | Note |
|---|---|:----:|---|
| **B+** | 7.4 V from KCD3 (+) | 14 AWG red | Motor power |
| **B−** | 7.4 V from KCD3 (−) | 14 AWG black | Motor ground |
| **M+** | Motor + terminal | 14 AWG | |
| **M−** | Motor − terminal | 14 AWG | |
| **VCC** (logic) | 5 V from LM2596 #1 | Dupont | |
| **GND** (logic) | Common GND | Dupont | ⚠️ star-grounded |
| **R_EN** | ESP32-S3 **GPIO 38** | Dupont | HIGH = enabled |
| **L_EN** | ESP32-S3 **GPIO 39** | Dupont | HIGH = enabled |
| **RPWM** | ESP32-S3 **GPIO 40** | Dupont | LEDC Ch0 — forward |
| **LPWM** | ESP32-S3 **GPIO 41** | Dupont | LEDC Ch1 — reverse |

> R_EN and L_EN must be HIGH for the driver to run. The firmware does that in `setup()`. If the motor doesn't spin, multimeter these two first — should read 3.3 V.

### 3.2. Direction test

1. Wire everything per the table.
2. Flash the bench-test firmware (target 10).
3. Send the `f` (forward) command in Serial Monitor.
4. If the wheels spin **backwards**, swap M+ and M− at the BTS7960.

✅ **Stage 3 checklist:**
- [ ] Motor turns the right way on "forward"
- [ ] BTS7960 isn't hot at idle (warm = OK; hot = ⛔)
- [ ] Motor caps installed (stage 2)

---

## Stage 4: Steering servo

> ⏱️ ~1 hour | 🟢 Easy

### 4.1. JX PDI-6221MG wiring (v13)

| Servo wire | Goes to | Color |
|:---:|---|:-----:|
| **+** (power) | 5 V from LM2596 #1 | Red |
| **−** (ground) | Common GND | Brown |
| **Signal** | ESP32-S3 **GPIO 42** | Orange |

> ⛔ **Do NOT** power the servo from the ESP32-S3's 3.3 V pin. The PDI-6221MG draws up to **2.5 A** under load and will fry the onboard regulator instantly.

### 4.2. Center calibration

Use the dedicated sketch [`sketches/servo_calibrate/servo_calibrate.ino`](../sketches/servo_calibrate/servo_calibrate.ino) — it walks you through fine-tuning center / left / right with `+` `-` keys and prints the values to paste into `wro_hw_config_v13.h`.

### 4.3. Range test

After calibration the servo should swing left ↔ right without buzzing or binding. If it stalls at an end-stop, increase `SERVO_MARGIN_US` in `wro_config_v13.h` (default 60 µs).

✅ **Stage 4 checklist:**
- [ ] Servo centered (wheels straight at SERVO_CENTER_US)
- [ ] Full range left to right is smooth
- [ ] Servo runs from 5 V (LM2596), not from the ESP32-S3
- [ ] Tie rod connected to the horn

---

## Stage 5: ESP32-S3 main board

> ⏱️ ~1 hour | 🟢 Easy

### 5.1. Mount

1. Drop the ESP32-S3-DevKitC-1 into a breadboard or sockets via header pins.
2. Mount the breadboard to the chassis with 3M VHB.
3. Keep the **USB-C port accessible** for flashing and debug.

> ⚠️ Keep the ESP32-S3 **at least 5 cm from the motor and BTS7960**. Motor EMI corrupts I2C and UART otherwise.

### 5.2. Star ground (critical!)

The most common failure cause is no common ground. All grounds meet at **one point** on the breadboard:

```
                   ┌── ESP32-S3 GND
                   ├── BTS7960 logic GND
common GND ────────┼── LM2596 #1 GND
(one node)         ├── LM2596 #2 GND
                   ├── OpenMV GND
                   └── every sensor GND
```

> ⛔ **Do NOT** chain GND through the components in series. That creates ground loops; I2C will fail intermittently.

### 5.3. Power the ESP32-S3

| ESP32-S3 pin | Connection |
|:---:|---|
| **VIN** (or 5V) | 5 V from LM2596 #1 |
| **GND** | Common GND |

> ⛔ **Do NOT power VIN and USB at the same time.** When debugging via USB-C, disconnect VIN.

### 5.4. What can/can't go through the breadboard

The breadboard is a signal/distribution bus, not a power bus. OK to route:
- GPIO signals (PWM, UART, I2C)
- Sensor 3.3 V supplies
- The single star-GND node

Do NOT route:
- Motor power (7.4 V → BTS7960)
- Servo 5 V under load (up to 2.5 A)
- Any line >0.5 A

Recommendation: run the servo's 5 V on its **own pair** straight from LM2596, with a 470-1000 µF electrolytic close to the servo.

✅ **Stage 5 checklist:**
- [ ] ESP32-S3 powers on at 5 V (status LED present)
- [ ] Serial Monitor talks at 115200 baud
- [ ] Common GND verified (multimeter shows 0 Ω between every GND)
- [ ] ESP32-S3 mounted >5 cm from motor

---

## Stage 6: Dual I2C buses

> ⏱️ ~2 hours | 🟡 Medium

### 6.1. Why two buses (instead of a TCA9548A mux)

The v11 build used a TCA9548A I2C multiplexer to share the bus across two AS5600 encoders (both fixed at `0x36`) and two VL53L1X sensors (both default `0x29`). **The mux burned out and is gone.** v13 takes a different approach:

- **AS5600 conflict** is solved by the bus split — one AS5600 on `Wire` (I2C0), the other on `Wire1` (I2C1). The ESP32-S3 has two native I2C peripherals.
- **VL53L1X conflict** is solved at boot via XSHUT pins: hold every VL53L1X in reset, bring them up one at a time, and rewrite each one's I2C address in RAM.

### 6.2. I2C0 wiring (Wire)

| ESP32-S3 pin | Signal | Devices on this bus |
|:---:|---|---|
| **GPIO 8** | SDA | ICM-20948 (0x68) + AS5600 Left (0x36) + VL53L1X Front (0x29 → 0x30) |
| **GPIO 9** | SCL | same |

### 6.3. I2C1 wiring (Wire1)

| ESP32-S3 pin | Signal | Devices on this bus |
|:---:|---|---|
| **GPIO 11** | SDA | AS5600 Right (0x36) + VL53L1X Side (0x29 → 0x31) |
| **GPIO 12** | SCL | same |

### 6.4. Pull-ups (mandatory)

> The ESP32-S3 internal pull-ups are weak (~45 kΩ). At 400 kHz with >10 cm wires they're not enough.

Each I2C bus needs **4.7 kΩ pull-ups**:
- **SDA → 3.3 V**
- **SCL → 3.3 V**

Many breakout boards already have these populated. Verify with a meter before adding more — too many in parallel pulls the bus too hard. Aim for ~2.5 kΩ effective.

> Wire length: keep each bus under ~30 cm. If you must go longer, drop `Wire.setClock()` from 400000 to 100000.

### 6.5. Diagnostic — run the dual-bus I2C scanner

1. In `wro_build_target.h`, set `WRO_ACTIVE_TARGET = 2` (`WRO_TARGET_SCAN_I2C`).
2. Flash and open Serial Monitor at 115200.
3. Expected output (BEFORE VL53L1X are remapped — the scanner runs before the main firmware):
```
=== I2C0 (Wire) ===
  0x68 -- ICM-20948 IMU (AD0 -> GND)
  0x36 -- AS5600 magnetic encoder
  0x29 -- VL53L1X (default - pre-remap)

=== I2C1 (Wire1) ===
  0x36 -- AS5600 magnetic encoder
  0x29 -- VL53L1X (default - pre-remap)
```

> **0x70** = TCA9548A mux. If you see that, you're scanning the wrong board (the mux is gone in v13).

### 6.6. Recovery / rollback procedure

If the bus is unstable after two scanner runs, fall back to a minimal config:
1. Power off (KCD3 OFF), wait 10 s.
2. Disconnect the AS5600 / VL53L1X — leave only the ICM-20948 on I2C0.
3. Run the scanner — only `0x68` should appear.
4. Add devices **one at a time** in this order: AS5600 Left, VL53L1X Front (I2C0), AS5600 Right (I2C1), VL53L1X Side (I2C1). Run the scanner after each addition.
5. Whichever device drops other devices off the bus = the one with the wiring fault.

Pass criterion: 3 consecutive scans with stable address lists.

✅ **Stage 6 checklist:**
- [ ] I2C0 scanner finds 0x68 + 0x36 + 0x29
- [ ] I2C1 scanner finds 0x36 + 0x29
- [ ] 4.7 kΩ pull-ups present on both buses
- [ ] No 0x70 (mux is supposed to be gone)
- [ ] Wires under 30 cm

---

## Stage 7: AS5600 encoders

> ⏱️ 3-4 hours | 🔴 Hardest mechanical step

### 7.1. How AS5600 works

AS5600 is a 12-bit magnetic encoder. A diametrically magnetized Ø6 mm magnet glued to a rotating shaft is read via Hall sensors → 4096 positions per revolution.

### 7.2. Magnet mounting

> ⛔ **The hardest mechanical step.** The magnet must sit **directly above the chip center**, with a **0.5-3 mm air gap**. >1 mm offset from center = invalid data.

Per encoder (Left → I2C0, Right → I2C1):

1. Find a shaft that rotates in lock-step with the wheel (half-shaft / drive cup).
2. Glue the Ø6 mm magnet to the **end of the shaft**:
   - Tiny drop of super glue (don't get glue on the face that talks to the chip), or
   - Thin 3M double-sided tape.
3. Mount the AS5600 PCB **facing the magnet**, 1-2 mm gap.
4. **Test:** rotate the wheel by hand; the AS5600 reading should sweep smoothly 0 → 4095 → 0.

### 7.3. Wiring (one per bus)

| AS5600 pin | Goes to (Left enc) | Goes to (Right enc) |
|:---:|---|---|
| VCC | 3.3 V | 3.3 V |
| GND | Common GND | Common GND |
| SDA | ESP32-S3 **GPIO 8** (I2C0) | ESP32-S3 **GPIO 11** (I2C1) |
| SCL | ESP32-S3 **GPIO 9** (I2C0) | ESP32-S3 **GPIO 12** (I2C1) |
| DIR | GND or floating | GND or floating |

### 7.4. Sanity-check in firmware

Set `WRO_ACTIVE_TARGET = 8` (`WRO_TARGET_TEST_ENCODERS`), flash, and watch Serial. While turning each wheel by hand:
- ✅ raw value sweeps 0 → 500 → 1000 → ... → 4095 → 0 smoothly
- ⛔ jumps >100 ticks per sample = magnet too far away or off-center

### 7.5. Magnet recovery / rollback

If readings are noisy (jumps, periodic -1, sudden odometry resets):
1. Power off.
2. Pull the AS5600 PCB and gently remove the magnet with tweezers.
3. Clean glue residue with isopropyl alcohol.
4. Re-glue the magnet centered, 1-2 mm gap, retest.
5. If the issue stays, swap the Left and Right modules — that proves whether the fault is in the PCB or the mount.

Symptom dictionary:
- jumps >100 / sample → magnet off-center
- periodic dropouts → gap too large
- random `SAFE_STOP` from encoder fail-counter → poor mechanical fixation, magnet shifts under vibration

✅ **Stage 7 checklist:**
- [ ] Left encoder visible at 0x36 on I2C0
- [ ] Right encoder visible at 0x36 on I2C1
- [ ] Left wheel: smooth value change when rotating by hand
- [ ] Right wheel: smooth value change when rotating by hand
- [ ] Magnets are firmly attached (shake the robot — they should not move)

---

## Stage 8: IMU (ICM-20948)

> ⏱️ ~2 hours | 🟡 Medium

### 8.1. GY-ICM20948V2 wiring (v13: AD0 → GND)

| IMU pin | Goes to | Note |
|:---:|---|---|
| VCC | 3.3 V | ⚠️ Not 5 V! |
| GND | GND | |
| SDA | ESP32-S3 **GPIO 8** (I2C0) | shares the bus with AS5600 Left + VL53L1X Front |
| SCL | ESP32-S3 **GPIO 9** (I2C0) | |
| AD0 | **GND** | Address = 0x68 |

> ⚠️ AD0 must go to **GND**. The v13 firmware expects **0x68**. (v11 used 0x69 with AD0 = VCC; the convention changed during the v12/v13 work.)

### 8.2. Mounting

1. Mount the IMU **horizontally** (Z axis up).
2. X axis points **forward**.
3. **Vibration isolation (mandatory):** 3 mm foam + 3M tape between IMU and chassis.

> Without isolation the gyro drifts 3-5× faster from motor vibration.

### 8.3. Gyro calibration

Automatic at boot (`imu_calibrate_gyro()`):
- Robot stays still for 3 seconds.
- Averages 300 Z-axis samples.
- Result is `gyroZbias`. If bias > 0.05 you have vibration.

### 8.4. IMU recovery / rollback

If the IMU misbehaves:
1. Verify VCC = 3.3 V, AD0 = GND, address = 0x68.
2. Recalibrate with the robot fully still (wheels off the ground).
3. Disconnect the motor temporarily and recalibrate to isolate vibration.

Roll-back rules:
- `gyroZbias > 0.05` two runs in a row → revisit the foam isolation
- Static yaw drift >2°/30 s → replace the I2C wires and shorten them
- IMU drops off the scanner intermittently → redo Stage 6.6

✅ **Stage 8 checklist:**
- [ ] IMU visible at 0x68 on I2C0
- [ ] `imu_calibrate_gyro()` bias < 0.05
- [ ] Yaw moves smoothly when you rotate the robot by hand
- [ ] IMU is on foam, level, X axis forward

---

## Stage 9: OpenMV H7 Plus camera

> ⏱️ ~2 hours | 🟡 Medium

### 9.1. UART2 wiring (ESP32-S3 ↔ OpenMV)

| OpenMV pin | ESP32-S3 pin | Description |
|:---:|:---:|---|
| **P4 (TX)** | **GPIO 17 (RX)** | Camera transmits → ESP32-S3 receives |
| **P5 (RX)** | **GPIO 18 (TX)** | ESP32-S3 transmits → camera receives |
| **GND** | **GND** | Common ground |
| **VIN** | **5 V from LM2596 #1** | Camera power |

> ⛔ **TX ↔ RX must be crossed!** TX → TX won't fry anything but no data flows.
> Levels: OpenMV H7 Plus is 3.3 V logic; ESP32-S3 is 3.3 V; **no level shifter needed**.

### 9.2. Mounting

| Parameter | Value | Why |
|---|:-----:|-----|
| Camera height above floor | **8-12 cm** | Sees both pillars and lines |
| Downtilt | **10-15°** (12° ideal) | Far pillars + nearby lines |
| Orientation | Lens forward | Direction of travel |
| Fixation | Rigid! 3M + zip tie | Vibration → blob jitter → false detections |

What goes wrong with bad mounting:
- Too horizontal → can't see orange/blue lines on the floor
- Too steep → can't see far pillars (>60 cm)
- Vibration → blobs "jump" → PID jitters the steering

### 9.3. Loading the OpenMV firmware

1. Connect OpenMV to a computer over **USB** (not UART).
2. Open OpenMV IDE.
3. Open `src/openmv/openmv_main.py`.
4. ⛔ Don't save to the camera yet — calibrate the thresholds first (Stage 15).
5. Press ▶ to test — you should see live frame buffer output.

✅ **Stage 9 checklist:**
- [ ] OpenMV IDE sees the camera over USB
- [ ] Frame buffer shows live image
- [ ] UART: anything (even noise) reaches ESP32-S3 Serial Monitor
- [ ] Camera is rigid, no rattle when you tap the chassis
- [ ] 8-12 cm height, ~12° downtilt
- [ ] 📸 Camera mount photo for `v-photos/`

---

## Stage 10: VL53L1X ToF sensors

> ⏱️ ~2 hours | 🟡 Medium

### 10.1. Mounting

**Front sensor (I2C0):**
- Front of the chassis, laser pointing **horizontally forward**
- Height: 3-5 cm above floor
- Sees the wall directly ahead — feeds the corner-detection FSM

**Side sensor (I2C1):**
- Right (or left) side of the chassis, laser pointing perpendicular to travel
- Height: 3-5 cm above floor
- Wall-following on Open Challenge straights

### 10.2. Wiring

Each VL53L1X needs an XSHUT pin so the firmware can hold it in reset during the boot-time address-remap dance.

| VL53L1X pin | Front | Side |
|:---:|---|---|
| VIN | 5 V | 5 V |
| GND | Common GND | Common GND |
| SDA | ESP32-S3 GPIO 8 (I2C0) | ESP32-S3 GPIO 11 (I2C1) |
| SCL | ESP32-S3 GPIO 9 (I2C0) | ESP32-S3 GPIO 12 (I2C1) |
| **XSHUT** | ESP32-S3 **GPIO 15** | ESP32-S3 **GPIO 16** |
| GPIO1 (interrupt) | floating | floating |

The third XSHUT pin (`GPIO 47`) is reserved for an optional 3rd VL53L1X on I2C0.

### 10.3. Library

Arduino IDE → Library Manager → search `VL53L1X` → install **VL53L1X by Pololu**.

### 10.4. Test

Set `WRO_ACTIVE_TARGET = 9` (`WRO_TARGET_TEST_VL53L1X`), flash, open Serial Monitor. Both sensors should report distances in mm. Wave a hand 20 cm away → ~200 mm.

✅ **Stage 10 checklist:**
- [ ] Front and side VL53L1X visible **after the boot-time remap** at 0x30 (front) and 0x31 (side)
- [ ] Distances change smoothly when you wave a hand near each sensor
- [ ] XSHUT pins are wired (not floating)

---

## Stage 11: E-Stop button

> ⏱️ ~30 minutes | 🟢 Easy

### 11.1. Wiring

Simple: a push-button between **GPIO 21** and **GND**:
```
3.3V ──[ESP32-S3 internal pull-up]── GPIO 21 ──[BUTTON]── GND
```
The firmware uses `INPUT_PULLUP`:
- Released → GPIO 21 = HIGH
- Pressed → GPIO 21 = LOW → E-Stop active

> Add a 10 kΩ pull-up to 3.3 V if you want belt-and-braces, but the internal pull-up is normally enough.

### 11.2. How E-Stop behaves in the firmware

| Action | Robot reaction |
|---|---|
| Press in `RS_INIT` | LED arms / fast blink |
| Release in `RS_INIT` | 🏁 **Race starts** — transition to `RS_RUN_*` |
| Press during the race | ⛔ Motor 0, steering centered, `RS_SAFE_STOP` |
| Release during the race | ▶️ Resume to the previous running state |

500 ms boot grace prevents a held button at power-up from arming the robot.

### 11.3. Mode selection (compile-time only — Rule 9.9)

For v13: edit `src/esp32/wro_config_v13.h`:
```cpp
#define OBSTACLE_MODE  0   // 0 = Open Challenge, 1 = Obstacle Challenge
```

✅ **Stage 11 checklist:**
- [ ] Button press → Serial logs the E-Stop transition
- [ ] Release → race starts / resumes
- [ ] Button is reachable from outside the robot
- [ ] Mode is set via `#define`, no physical switches

---

## Stage 12: Status LED

> ⏱️ ~15 minutes | 🟢 Easy

### 12.1. Wiring

```
ESP32-S3 GPIO 2 ──[220 Ω]──[LED anode (+)]──[LED cathode (−)]── GND
```

Use a bright LED (blue or white) — needs to be visible from 2+ meters.

### 12.2. Signal map

| LED behavior | Robot state | Meaning |
|:---:|---|---|
| Slow blink (~1 Hz) | `RS_INIT` / `RS_WAIT_START` | Press + release E-Stop to start |
| Solid on | `RS_RUN_OPEN` / `RS_RUN_OBS` | Race in progress |
| Fast blink (~4 Hz) | `RS_FINISH` | 🏁 Done after 3 laps |
| Off | `RS_SAFE_STOP` | E-Stop held / fault |

✅ **Stage 12 checklist:**
- [ ] LED on at GPIO 2 = HIGH
- [ ] LED off at GPIO 2 = LOW
- [ ] Visible from 2+ m

---

## Stage 13: Final wire dressing

> ⏱️ 2-3 hours | 🟡 Medium
>
> ⚠️ Sloppy wiring causes 80% of competition failures. Spend the time now.

### 13.1. Routing rules

| Rule | Why |
|---|-----|
| Power and signal wires NOT parallel | EMI from 7.4 V/8 A line couples into I2C |
| Power (LiPo → BTS → motor) on **one** side of the chassis | Isolate noise |
| Signal (I2C, UART, PWM) on the **other** side | Clean signal |
| Cable tie every 5-7 cm | Vibration won't yank connectors |
| Slack on the steering servo wires | Servo turns — wires must not pull |

### 13.2. Vibration-proofing

1. Every Dupont connector — drop of hot glue at the joint.
2. Tug-test every soldered wire.
3. Breadboard fixed with both 3M tape and a cable tie through the mounting holes.

### 13.3. Final continuity check

| # | Test | Expected | If wrong |
|:-:|---|:---:|---|
| 1 | Short: 7.4 V+ ↔ GND | open | ⛔ Find and remove |
| 2 | Short: 5 V+ ↔ GND | open | ⛔ |
| 3 | Short: 3.3 V+ ↔ GND | open | ⛔ |
| 4 | All component GNDs | 0 Ω among them | No common GND — fix |
| 5 | SDA ↔ SCL on each bus | not shorted | Wires crossed |

✅ **Stage 13 checklist:**
- [ ] Power and signal wires routed on opposite sides
- [ ] All wires zip-tied
- [ ] No dangling conductors
- [ ] No shorts
- [ ] Dupont connectors hot-glued
- [ ] 📸 Final harness photo

---

## Stage 14: Firmware flashing

> ⏱️ ~2 hours | 🟡 Medium

### 14.1. Arduino IDE setup

1. **ESP32 board package:**
   - File → Preferences → Additional Board Manager URLs:
     `https://raw.githubusercontent.com/espressif/arduino-esp32/gh-pages/package_esp32_index.json`
   - Tools → Board Manager → install `esp32` by Espressif (v3.x).
2. **Libraries:**
   - `ESP32Servo`
   - `Adafruit ICM20948`
   - `Adafruit Unified Sensor`
   - `VL53L1X` by Pololu
   - (AS5600 driver is inline in `as5600_dual_i2c.h` — no library install needed)
3. **Board settings:**

| Setting | Value |
|---|---|
| Board | **ESP32S3 Dev Module** |
| USB CDC On Boot | **Enabled** |
| Upload Speed | 921600 |
| Flash Size | 8MB |
| PSRAM | OPI PSRAM |
| Partition Scheme | Default |
| Port | (your ESP32-S3 port) |

### 14.2. Flashing the ESP32-S3

1. Open `src/esp32/` as a sketch in Arduino IDE.
2. Verify `src/esp32/wro_hw_config_v13.h`:
   - `TICKS_PER_CM` = your measured value (Stage 1)
   - `SERVO_*_US` = your measured values (Stage 4 / sketch)
3. Verify `src/esp32/wro_config_v13.h`:
   - `OBSTACLE_MODE` = 0 (Open) or 1 (Obstacle)
   - `HAS_SIDE_TOF` = 1 if side VL53L1X is wired
4. In `src/esp32/wro_build_target.h`, ensure `WRO_ACTIVE_TARGET = WRO_TARGET_V13_MAIN` (= 11).
5. **Compile** (Ctrl+R) — ensure no errors.
6. **Upload** (Ctrl+U).
7. Open Serial Monitor at 115200. Expected boot output:
```
============================================================
 WRO FE 2026 -- Team Faith -- v13.0 main firmware
 Mode: OPEN CHALLENGE
 WiFi: OFF, BT: OFF (Rule 11.10)
============================================================
AS5600 dual I2C: OK
VL53L1X FRONT: OK at 0x30
VL53L1X SIDE:  OK at 0x31
ICM-20948 IMU: OK
Calibrating gyro Z bias............
Gyro Z bias = 0.00234 rad/s
System ready. Press E-Stop to start.
```

### 14.3. Flashing the OpenMV

1. Connect OpenMV via USB.
2. Open OpenMV IDE.
3. Open `src/openmv/openmv_main.py`.
4. **Calibrate thresholds first** (Stage 15.1).
5. Tools → Save Script to OpenMV Cam → save as `main.py`. The camera will run autonomously on next power cycle.

### 14.4. Integration smoke test (mandatory before Stage 15)

Goal: confirm every subsystem works **together** before fine calibration.

1. Power on, wait for `System ready.` in Serial Monitor.
2. Start logic: press + release the E-Stop → state transitions correctly INIT → WAIT_START → RUN.
3. Emergency stop: press during a (wheels-up) run → motor 0, steering centered.
4. Camera: with OpenMV connected, the firmware logs valid camera frames; if you unplug the camera, after `CAM_SILENT_DEGRADE_MS` you should see a warning.
5. Lap counting (dry): turn the chassis by hand through 360°; the gyro lap counter should tick.

Pass: every step works without an unexpected reboot or sensor dropout.
Fail: revisit Stages 6-9 before continuing.

✅ **Stage 14 checklist:**
- [ ] ESP32-S3 flashes without errors
- [ ] Serial Monitor reports "System ready."
- [ ] Gyro calibration `gyroZbias < 0.05`
- [ ] E-Stop press/release reflected in Serial
- [ ] OpenMV IDE sees the camera
- [ ] Smoke test passes

---

## Stage 15: Calibration and first run

> ⏱️ 4-6 hours | 🔴 The most important stage

### 15.1. Color thresholds (OpenMV)

> ⛔ Wrong thresholds → robot doesn't see pillars → crashes → DQ. Calibrate under the **same lighting** as the competition.

For each color:
1. Connect OpenMV via USB and open `openmv_main.py`.
2. Place the robot near the target object.
3. **Tools → Machine Vision → Threshold Editor**.
4. Aim the camera at the target.
5. Drag the L / A / B sliders until only the target shows up in the mask.
6. Record (L_min, L_max, A_min, A_max, B_min, B_max) and paste into the matching `THRESHOLD_*` constant in the script.

| # | Color | Variable | Object |
|:-:|:-----:|---|---|
| 1 | 🟠 | `THRESHOLD_ORANGE` | Orange line on the mat |
| 2 | 🔵 | `THRESHOLD_BLUE` | Blue line on the mat |
| 3 | 🔴 | `THRESHOLD_RED` | Red pillar |
| 4 | 🟢 | `THRESHOLD_GREEN` | Green pillar |
| 5 | 🩷 | `THRESHOLD_MAGENTA` | Magenta parking block |
| 6 | ⬛ | `THRESHOLD_WALL` | Black track wall |

### 15.2. Focal-length constant

1. Place a red pillar exactly **20 cm** from the camera.
2. Read raw `blob.w()` in the IDE.
3. `FOCAL_CONST = 20 × blob.w()`.
4. Update the constant in `openmv_main.py`.

### 15.3. Odometry calibration

Test conditions:
- Surface: flat mat / tile, no slope
- Motion: straight line, no steering input
- Distance: 100 cm with start/finish marks

1. Mark the start position of one wheel.
2. Run the robot 100 cm three times.
3. Each run, record `Δ totalDistLeft` from Serial Monitor.
4. `avg = (run1 + run2 + run3) / 3`
5. `TICKS_PER_CM = avg / 100`
6. Update `TICKS_PER_CM` in `wro_hw_config_v13.h`, reflash, repeat once.

Pass: ≤ 2 cm error on a 100 cm run.
Fail: >2 cm → repeat steps 2-6.

### 15.4. First run — on the floor (NOT on the track)

1. Smooth floor (not the track yet).
2. KCD3 ON.
3. LED slow blink → `RS_INIT` ✅
4. Press E-Stop → fast blink → release → solid on = race ✅
5. Press E-Stop → robot stops ✅
6. Release → robot resumes ✅

### 15.5. First lap — Open Challenge

1. `OBSTACLE_MODE 0` → reflash.
2. Place on track (no pillars).
3. Run.
4. Robot should complete **3 laps and stop**.
5. If not, read Serial telemetry to debug.

### 15.6. Lap — Obstacle Challenge

1. `OBSTACLE_MODE 1` → reflash.
2. Place red and green pillars on the track.
3. Run.
4. Red → keep right; green → keep left.
5. 3 laps → parking between magenta blocks.

### 15.7. Live PID tuning

During a run you can change PID gains over USB Serial in real time:

| Command | Example | Effect |
|:---:|---|---|
| `P0.65` | Kp = 0.65 | Sharper steering correction |
| `D0.25` | Kd = 0.25 | More damping (less oscillation) |
| `I0.003` | Ki = 0.003 | More integral (kills steady drift) |
| `G1.50` | Gyro Kp = 1.50 | Stronger heading correction |
| `S+` / `S-` | — | Bump max speed ±5 PWM |
| `?` | — | Full state dump |
| `!` | — | Software E-Stop |

Defaults from `wro_config_v13.h`: `PILLAR_KP=0.45`, `PILLAR_KI=0.001`, `PILLAR_KD=0.30`, `HEADING_KP=12.0`. Tune from there.

✅ **Final checklist:**
- [ ] All 6 colors calibrated in OpenMV
- [ ] FOCAL_CONST recorded: ___
- [ ] TICKS_PER_CM recorded: ___
- [ ] E-Stop works (stop + resume)
- [ ] Open Challenge: 3 laps + stop
- [ ] Obstacle Challenge: pillars + parking
- [ ] LED shows correct states
- [ ] 📸 Successful-run video captured for `video/`

---

## Common problems and fixes

### 🔌 I2C issues

| Symptom | Cause | Fix |
|---|---|-----|
| Robot freezes after 5-10 s | Motor EMI on I2C | 0.1 µF caps on motor (3 of them) |
| Encoders drop out | Long wires + 400 kHz | Shorter wires, or `Wire.setClock(100000)` |
| Scanner finds nothing | Missing pull-ups | Add 4.7 kΩ on SDA + SCL of each bus |
| IMU bias > 0.1 | Vibration during calibration | Robot still + foam isolation |
| All sensors disappear at once | No common GND | Verify 0 Ω between every GND |

### 🎥 Camera doesn't see colors

| Symptom | Cause | Fix |
|---|---|-----|
| All thresholds fail | Auto exposure / white balance still on | `auto_gain=False, auto_whitebal=False` |
| Color "moved" under different lighting | Calibrated under different lighting | Recalibrate on site with Threshold Editor |
| Confuses red and orange | LAB ranges overlap | Tighten ranges in Threshold Editor |
| No UART data | TX/RX not crossed | Swap RX↔TX |

### 🏎️ Robot drives crooked

| Symptom | Cause | Fix |
|---|---|-----|
| Drifts left/right | SERVO_CENTER_US off | Re-run `sketches/servo_calibrate` |
| Twitchy steering | Noisy PID derivative | Lower `PILLAR_DERIV_EMA_A` (0.2-0.3) |
| Misses corners | `TURN_TARGET_DEG` too low | Raise to 88-92° |
| Crosses start line late | Lap cooldown too long | Lower `LAP_COOLDOWN_MS` |
| Steering oscillates | Kp too high | Drop with `P0.40` over Serial |

### 🔋 Power

| Symptom | Cause | Fix |
|---|---|-----|
| ESP32-S3 reboots when motor starts | 5 V sag | 470 µF on the 5 V rail |
| Servo jitters | LM2596 can't deliver 2 A+ | Verify LM2596 under load |
| Battery sags | Below 6.4 V | LiPo tester with alarm |

---

## 🏆 Competition tips

1. **Print** this guide and bring it to WRO.
2. **Spares:** Dupont jumpers, an extra ESP32-S3, zip ties, 3M tape, insulating tape.
3. **Write down** working color thresholds on paper as a fallback.
4. **Charge** the LiPo to 8.4 V before each round.
5. **Warm up** the robot with one practice lap so the gyro stabilizes.

---

> *"Engineering is the closest thing to magic that exists in the world."*
>
> **— Team Faith**

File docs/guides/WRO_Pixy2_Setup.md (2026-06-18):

# Pixy2/2.1 — временная камера вместо OpenMV (v13)

**Контекст:** 2026-06-12 повреждён сенсор-модуль OpenMV H7 Plus. Pixy подключается
на **те же пины UART2**, прошивка робота уже умеет оба бэкенда
(`CAMERA_BACKEND` в `wro_config_v13.h`, §12 — сейчас стоит `PIXY2`).
FSM, failsafe-логика и телеметрия не менялись.

---

## 1. Какая у нас Pixy?

- **Pixy2 / Pixy2.1** — маленькая (~40 мм), кнопка сверху. → всё по этому гайду.
- **Pixy1 (CMUcam5)** — большая плата ~55 мм, 2014 года. → СТОП, протокол другой,
  сказать Claude — драйвер нужен другой.

## 2. Подключение к роботу

10-пиновый разъём Pixy (IDC 2×5, пин 1 помечен стрелкой/треугольником):

| Pixy | Провод | ESP32-S3 |
|---|---|---|
| pin 4 (UART TX) | → | GPIO17 (CAMERA_RX) |
| pin 1 (UART RX) | ← | GPIO18 (CAMERA_TX) |
| pin 2 (5V) | ← | 5V с бака (Pixy ест ~140 мА) |
| pin 6 (GND) | ↔ | GND |

Логика Pixy — 3.3 В, для S3 совместимо напрямую.

## 3. PixyMon: один раз настроить

1. Установи PixyMon v2 (pixycam.com → downloads), подключи Pixy по USB.
2. **Интерфейс:** Configure → Interface → `Data out port` = **UART**,
   `UART baudrate` = **115200** (заводское 19200 — обязательно сменить!).
3. **Сигнатуры — учить строго в этом порядке** (прошивка робота ждёт именно так):
   - **1 = красный столбик**
   - **2 = зелёный столбик**
   - **3 = оранжевая линия**
   - **4 = синяя линия**
   - **5 = маджента-парковка**

   Action → Set signature 1..5 (или кнопкой на камере). Учить **при том же
   свете, что и заезд**, объект на 30–60 см.
4. Подкрути per-signature range так, чтобы блок держался стабильно, а пустая
   сцена не давала ложных блоков.
5. File → Save Parameters (сохранить во флеш Pixy).

## 4. Калибровка дистанции (FOCAL)

1. Красный столбик ровно на **50 см** от объектива.
2. Смотри в телеметрии робота `redDist` (камера должна быть подключена к S3).
3. Новое значение: `PIXY_FOCAL_PIX_new = PIXY_FOCAL_PIX_тек × redDist / 50`.
4. Впиши в `wro_config_v13.h` §12, перепрошей, проверь: на 50 см → ~50, на 100 см → ~100.

Дефолт 190 рассчитан на Pixy2.1 (~80°). У Pixy2 (60°) будет ближе к 270.

## 5. Проверка связки

1. Target 11 (`wro_v13_main.cpp`), боот-лог: `Camera UART2 ready — Pixy2 backend`.
2. Покажи камере красный столбик → в телеметрии `redDist` < 999 и `redX` меняется
   при движении столбика влево/вправо.
3. Зелёный → `greenDist/greenX`. Оранжевая/синяя линия на полу в нижней части
   кадра → биты ModeFlag. Маджента → бит 4 + extraTag.
4. Убери всё из кадра → дистанции 999, флаги 0, камера остаётся online.

⚠️ Target 12 (`diag_test_camera.cpp`) сделан под текстовый протокол OpenMV —
для Pixy он покажет мусор, это нормально. Проверяй через телеметрию target 11.

## 6. Вернуть OpenMV (если модуль оживёт / приедет новый)

`wro_config_v13.h` §12: `#define CAMERA_BACKEND CAMERA_BACKEND_OPENMV` → перепрошить.
Больше ничего менять не надо.

## Известные отличия от OpenMV

- Pixy сама делает экспозицию/баланс — фиксации, как на OpenMV, нет. Поэтому
  **переучить сигнатуры на месте соревнования** (5 минут) — обязательный пункт
  чек-листа.
- Дистанция считается из высоты блока Pixy — после смены камеры обязательно
  перекалибровать FOCAL (§4) и прогнать Dynamic Offset на треке.
- Крепление: у Pixy **3 отверстия ⌀3 мм** (НЕ 4 по углам), штатно идут винты
  4-40, но M2.5 тоже проходят. Координаты от угла платы: (5.1, 31.3) ·
  (16.0, 38.8) · (22.4, 38.8); объектив (19.0, 5.0); плата 38.25 × 42 мм
  (офиц. docs.pixycam.com/wiki/v2:dimensions). Старый OpenMV-маунт не подходит —
  печатать `models/Pixy2_mount/` (тот же footprint и наклон 15°, высота
  объектива как у OpenMV). До печати — хомут/стяжка.

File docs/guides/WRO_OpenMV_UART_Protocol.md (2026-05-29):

# OpenMV → ESP32-S3 UART Protocol v3.1

## Frame Format
```
RedX,RedDist,GreenX,GreenDist,ModeFlag,ExtraTag*XX\n
```

## Fields

| # | Field | Range | Description |
|---|---|---|---|
| 1 | `RedX` | -80..79 | X-position of red pillar (cx-80; use RedDist=999 for not-seen) |
| 2 | `RedDist` | 0..999 | Distance to red pillar (cm), 999 = not seen |
| 3 | `GreenX` | -80..79 | X-position of green pillar (cx-80; use GreenDist=999 for not-seen) |
| 4 | `GreenDist` | 0..999 | Distance to green pillar (cm), 999 = not seen |
| 5 | `ModeFlag` | 0..7 | Bit field — see below (bit 3 reserved/unused) |
| 6 | `ExtraTag` | -80..79 | X-position of magenta block (cx-80), or 0 |

Distances use the pinhole model `d = FOCAL_PIX * pillar_height / blob_h_px`,
with `pillar_height = 10 cm` per WRO 2026 FE rule 13.19.

## ModeFlag (bitwise)

| Bit | Value | Flag |
|-----|---|---|
| 0 | `1` | Orange line visible (CW indicator, rule 13.9) |
| 1 | `2` | Blue line visible (CCW indicator, rule 13.9) |
| 2 | `4` | Magenta parking block visible (rule 13.27) |
| 3 | `8` | RESERVED — wall distance is owned by ESP32 ToF sensors in v13. Camera always emits 0. |

## ExtraTag

- If `ModeFlag & 4` (magenta block visible) → X-position of the block (-80..79)
- Otherwise → `0`

## Example
```
-25,42,30,58,1,0*0F
```
Red pillar at X=-25, 42 cm | Green pillar at X=30, 58 cm | orange line visible | XOR checksum = 0F

## XOR Checksum
```
cs = XOR of every byte in the data string (everything before '*')
Format: 2-char uppercase hex after '*'
```

## Requirements
- Baud: `115200`, `8N1`
- Every frame ends with `\n`
- The `*XX` checksum is mandatory
- Exactly 5 commas = 6 fields
- ESP32-S3 timeout: `500 ms` → camera marked offline → fallback to gyro-only navigation
- Frame rate: ~50 Hz (camera caps with `time.sleep_ms(10)`)

## Compatibility
- Wire format is identical to v3.0; the only changes are semantics:
  bit 3 of `ModeFlag` is now reserved and always 0, and `ExtraTag` no
  longer carries a wall distance. The v13 ESP32 firmware does not consume
  bit 3 from the camera (legacy v11 did), so this is a documentation-only
  change for that field.

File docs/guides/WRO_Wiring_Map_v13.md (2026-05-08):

# WRO Wiring Map — v13

**Hardware revision:** v13.0 (ESP32-S3 + 2× AS5600 dual-I2C + 2× VL53L1X XSHUT-remap)
**Previous revisions:** v11 (ESP32 DevKitC V4 + AS5600 + VL53L1X via TCA9548A) → v12 (ESP32-S3 + AS5048A SPI + TFMini-S UART)
**Date:** May 2026

---

## Why v13 exists

v12 was the planned migration to AS5048A SPI encoders + TFMini-S UART distance sensors, sidestepping the I2C address conflicts that the v11 stack solved with a TCA9548A multiplexer. **The hardware never made it onto the robot:** the AS5048A and TFMini-S parts hadn't arrived, and meanwhile the TCA9548A on the v11 board burned out.

Rather than wait for the v12 parts, the team is shipping v13 — same v11 sensors (AS5600 + VL53L1X) but on the new ESP32-S3 main board, using **two native I2C peripherals** to split the AS5600 pair (one per bus) and **XSHUT-based address remapping** for the VL53L1X pair. No mux required.

---

## Bus Architecture

```
ESP32-S3-DevKitC-1 (N8R8)
│
├── I2C0 (Wire,  GPIO 8/9) ──── ICM-20948 IMU       (0x68)
│                            ├── AS5600 Left         (0x36)
│                            └── VL53L1X Front       (0x29 → 0x30)  XSHUT=GPIO15
│
├── I2C1 (Wire1, GPIO 11/12) ── AS5600 Right        (0x36)
│                            └── VL53L1X Side        (0x29 → 0x31)  XSHUT=GPIO16
│
├── UART2 (GPIO 17/18) ──────── OpenMV H7 Plus Camera
├── UART0 (USB-C native) ─────── Debug serial
│
├── LEDC (GPIO 40/41) ─────────  BTS7960 Motor Driver
└── PWM  (GPIO 42) ─────────────  JX PDI-6221MG Steering Servo
```

> **VL53L1X address remapping** runs once at boot, in `vl53l1x_dual.h`:
>   1. All XSHUTs driven LOW (every VL53L1X in reset).
>   2. Front XSHUT released → boots at 0x29 → reassigned to 0x30.
>   3. Side  XSHUT released → boots at 0x29 (different bus, no clash) → reassigned to 0x31.
> The new addresses live only in RAM, so the dance repeats every reset.

---

## Complete Pin Table

### I2C0 — Wire (3 devices)
| GPIO | Signal | Devices |
|:----:|---|---|
| 8 | SDA | ICM-20948 (0x68) + AS5600 Left (0x36) + VL53L1X Front (0x30) |
| 9 | SCL | same |

### I2C1 — Wire1 (2 devices)
| GPIO | Signal | Devices |
|:----:|---|---|
| 11 | SDA | AS5600 Right (0x36) + VL53L1X Side (0x31) |
| 12 | SCL | same |

### VL53L1X XSHUT pins
| GPIO | Sensor | Notes |
|:----:|---|---|
| 15 | VL53L1X Front XSHUT | I2C0 |
| 16 | VL53L1X Side XSHUT | I2C1 |
| 47 | (reserved) VL53L1X Third XSHUT | optional 3rd unit on I2C0 |

### UART2 — OpenMV Camera
| GPIO | Signal | Connected to |
|:----:|---|---|
| 17 | RX | OpenMV TX |
| 18 | TX | OpenMV RX |

### BTS7960 Motor Driver
| GPIO | Signal | |
|:----:|---|--|
| 38 | R_EN | Right enable |
| 39 | L_EN | Left enable |
| 40 | R_PWM | Forward (LEDC Ch0) |
| 41 | L_PWM | Reverse (LEDC Ch1) |

### Steering Servo
| GPIO | Signal | |
|:----:|---|--|
| 42 | PWM | JX PDI-6221MG |

### Control
| GPIO | Signal | |
|:----:|---|--|
| 21 | E-Stop | INPUT_PULLUP button |
| 2 | Status LED | |
| 48 | RGB LED | WS2812 onboard (DevKit silkscreen) |

---

## Power
- **5V rail:** ESP32-S3 VIN, OpenMV, JX servo (high current!)
- **3.3V rail:** ICM-20948, 2× AS5600, 2× VL53L1X (from ESP32-S3 onboard regulator)
- **Motor power:** LiPo 2S/3S → BTS7960 directly
- **Common GND** across all components is mandatory

> **VL53L1X powers from 2.6–5.5 V** via VIN; the breakout boards typically expose a 3.3 V LDO and accept 5 V on VIN. AS5600 needs 3.0–5.5 V. The ESP32-S3 onboard 3.3 V regulator is fine for both AS5600s and both VL53L1Xs together.

---

## Pull-ups
The ESP32-S3 has weak internal pull-ups. For reliable I2C at 400 kHz with 5 devices on a bus, add **external 4.7 kΩ pull-ups** from SDA→3.3V and SCL→3.3V, on each bus. The AS5600 breakout boards usually include them; the VL53L1X breakout typically does too. Verify with a meter — too many pull-ups in parallel will pull the bus too hard (target ~2.5 kΩ effective).

---

## What changed across revisions

| Component | v11 | v12 (planned, never wired) | v13 (current) |
|---|-----|---|---|
| MCU | ESP32 DevKitC V4 | ESP32-S3-DevKitC-1 N8R8 | ESP32-S3-DevKitC-1 N8R8 |
| Encoders | 2× AS5600 (I2C, 12-bit) | 2× AS5048A (SPI, 14-bit) | 2× AS5600 (I2C, 12-bit) |
| Distance front | VL53L1X (I2C, 4 m) | TFMini-S (UART, 12 m) | VL53L1X (I2C, ~3 m) |
| Distance side | VL53L1X (I2C) | TFMini-S (pending) | VL53L1X (I2C) |
| I2C mux | TCA9548A (0x70) | None | None — burned out, replaced by dual-bus + XSHUT |
| I2C buses | 2 (Wire + Wire1 via mux scheme) | 1 (Wire only) | 2 (Wire + Wire1 native peripherals) |
| Odometry | 277 ticks/cm | 1110 ticks/cm | 277 ticks/cm |
| Max distance | 4 m | 12 m | ~3 m (Medium mode, 50 ms budget) |

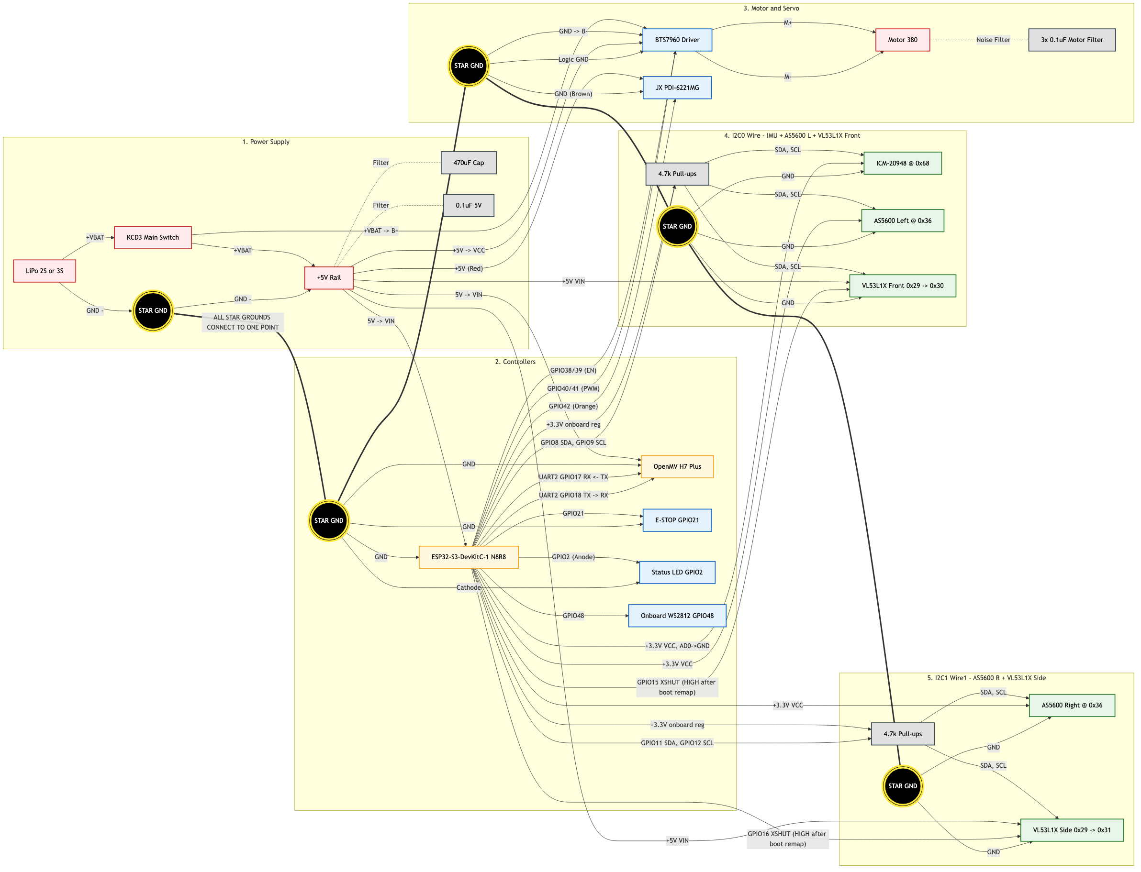
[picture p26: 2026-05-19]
schemes/WRO_Detailed_Wiring_Diagram.png

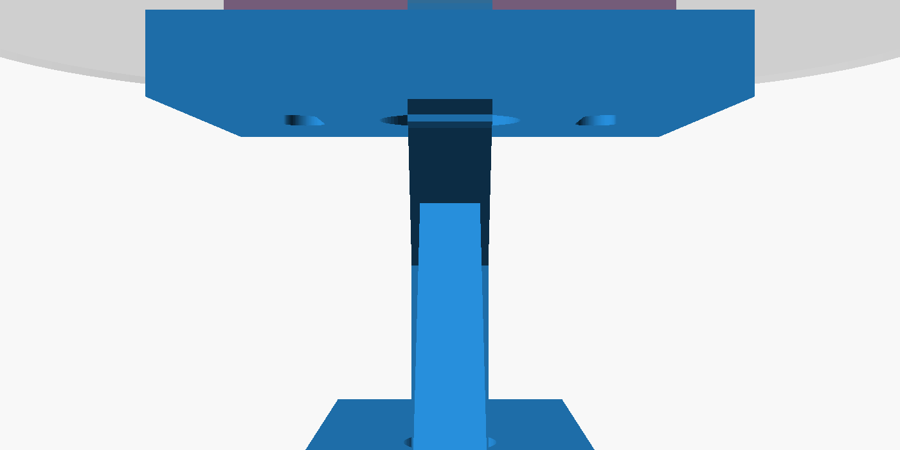
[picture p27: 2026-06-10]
models/AS5600_bracket/assembly_top.png

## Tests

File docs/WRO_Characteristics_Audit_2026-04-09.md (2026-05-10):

# WRO Characteristics Audit

Date: 9 April 2026 — **v11 historical audit, line numbers stale; v13 re-audit pending**
Scope: Compare documented template values with active firmware/runtime values

> ⚠️ **v13 status (May 2026):** This audit was performed against `src/esp32/eps323.cpp` (now `src/esp32/legacy/legacy_eps323.cpp`) and the line numbers below no longer point at active code. The active firmware is `src/esp32/wro_v13_main.cpp` plus modular `wro_*.{cpp,h}` files. Tunables now live in `src/esp32/wro_config_v13.h` (gains, thresholds, mode flag) and `src/esp32/wro_hw_config_v13.h` (pin map, encoder/odometry constants). A re-audit against the v13 sources is required.

Compared sources (v11 historical):
- `docs/WRO_Config_Template.h`
- `src/esp32/legacy/legacy_eps323.cpp` (was `src/esp32/eps323.cpp`)
- `src/openmv/openmv_main.py`

---

## 1) Summary

- Parameters fully aligned: 10
- Parameters requiring alignment or clarification: 8
- Main mismatch cluster: speed profile and PID defaults

Interpretation:
- Firmware appears intentionally tuned for race mode behavior.
- Template file appears generic and should be versioned per mode/tuning state.

---

## 2) ESP32 configuration comparison

| Parameter | Template value | Firmware value | Status | Anchor |
|---|---|---|---|---|
| Servo center | `CFG_SERVO_CENTER = 90` | `SERVO_CENTER = 90` | OK | `docs/WRO_Config_Template.h:7`, `src/esp32/eps323.cpp:54` |
| Servo max right | `135` | `135` | OK | `docs/WRO_Config_Template.h:8`, `src/esp32/eps323.cpp:55` |
| Servo max left | `45` | `45` | OK | `docs/WRO_Config_Template.h:9`, `src/esp32/eps323.cpp:56` |
| Motor max speed | `150` | `OBS=140`, `OPEN=180` | MISMATCH (mode-specific) | `docs/WRO_Config_Template.h:12`, `src/esp32/eps323.cpp:59`, `src/esp32/eps323.cpp:65` |
| Motor turn fast | `120` | `OBS=110`, `OPEN=140` | MISMATCH (mode-specific) | `docs/WRO_Config_Template.h:13`, `src/esp32/eps323.cpp:60`, `src/esp32/eps323.cpp:66` |
| Motor turn slow | `80` | `OBS=75`, `OPEN=95` | MISMATCH (mode-specific) | `docs/WRO_Config_Template.h:14`, `src/esp32/eps323.cpp:61`, `src/esp32/eps323.cpp:67` |
| Motor min speed | `35` | `OBS=35`, `OPEN=40` | PARTIAL MATCH | `docs/WRO_Config_Template.h:15`, `src/esp32/eps323.cpp:62`, `src/esp32/eps323.cpp:68` |
| PID Kp | `0.50` | `0.55` | MISMATCH | `docs/WRO_Config_Template.h:18`, `src/esp32/eps323.cpp:79` |
| PID Ki | `0.001` | `0.002` | MISMATCH | `docs/WRO_Config_Template.h:19`, `src/esp32/eps323.cpp:80` |
| PID Kd | `0.10` | `0.18` | MISMATCH | `docs/WRO_Config_Template.h:20`, `src/esp32/eps323.cpp:81` |
| Gyro Kp | `1.20` | `1.20` | OK | `docs/WRO_Config_Template.h:21`, `src/esp32/eps323.cpp:82` |
| Camera timeout (ms) | `500` | `500` | OK | `docs/WRO_Config_Template.h:24`, `src/esp32/eps323.cpp:139` |
| Loop interval (ms) | `10` | `10` | OK | `docs/WRO_Config_Template.h:25`, `src/esp32/eps323.cpp:142` |
| Encoder turn ticks | `3000` | `3000` | OK | `docs/WRO_Config_Template.h:28`, `src/esp32/eps323.cpp:151` |
| Target laps | `3` | `3` | OK | `docs/WRO_Config_Template.h:35`, `src/esp32/eps323.cpp:160` |
| Lap degrees | `360.0` | `360.0` | OK | `docs/WRO_Config_Template.h:36`, `src/esp32/eps323.cpp:161` |
| E-Stop debounce (ms) | `20` | `20` | OK | `docs/WRO_Config_Template.h:39`, `src/esp32/eps323.cpp:145` |
| Finish blink (ms) | `500` | `250` | MISMATCH | `docs/WRO_Config_Template.h:40`, `src/esp32/eps323.cpp:144` |

---

## 3) OpenMV characteristics baseline

| Parameter | Current value | Status | Anchor |
|---|---|---|---|
| UART | `UART(3, 115200, timeout_char=1000)` | OK | `src/openmv/openmv_main.py:32` |
| Auto gain | `False` | OK | `src/openmv/openmv_main.py:27` |
| Auto white balance | `False` | OK | `src/openmv/openmv_main.py:28` |
| Auto exposure | `False, exposure_us=10000` | OK | `src/openmv/openmv_main.py:29` |
| Focal constant | `2000` | TRACK-CALIBRATION REQUIRED | `src/openmv/openmv_main.py:66` |
| Color thresholds (LAB) | RED/GREEN/ORANGE/BLUE/MAGENTA/WALL set | TRACK-CALIBRATION REQUIRED | `src/openmv/openmv_main.py:40-45` |

---

## 4) Actions required

1. Split `WRO_Config_Template.h` into mode-specific templates (Open vs Obstacle) or annotate as baseline-only.
2. Align documented PID defaults with actual race-tuned firmware values.
3. Align finish blink documentation (`500 ms` vs `250 ms`) to avoid confusion in diagnostics.
4. Keep threshold and focal constant values in test logs per venue lighting.

---

## 5) Verification statement

This audit is document/code level only.
Physical validation still required on hardware for:
- true steering neutrality under load,
- battery sag impact on speed profile,
- final race behavior under official field conditions.

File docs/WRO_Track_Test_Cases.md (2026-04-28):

# WRO Track Test Cases

## How to run this file

- Execute test cases in order from TC-01 to TC-08.
- If any safety-critical test fails, stop and fix before continuing.
- Record every result in `docs/WRO_Test_Log.csv`.

## TC-01 Stand Safety Test

Goal:
- Verify no unexpected motion at startup.

Steps:
1. Place robot on stand (wheels off ground).
2. Power on and wait for ready state.
3. Observe steering and motor output for 10 seconds.

Pass criteria:
- Steering moves to center and remains stable.
- Motor output remains zero.
- No uncontrolled wheel rotation.

Fail action:
- Block floor tests.
- Inspect startup state logic and motor enable pins.

## TC-02 E-Stop Reaction

Goal:
- Verify emergency stop and safe resume behavior.

Steps:
1. Run robot at low speed on safe surface.
2. Press E-Stop.
3. Confirm stop behavior.
4. Release E-Stop and verify resume behavior.

Pass criteria:
- Press E-Stop -> motor = 0 and steering = center.
- Release E-Stop -> controlled resume only, no sudden jump.

Fail action:
- Block all race runs.
- Recheck GPIO32 wiring, debounce, and `safeStop()` path.

## TC-03 Camera Timeout Stop

Goal:
- Verify fail-safe behavior on camera data loss.

Steps:
1. Start run with valid camera stream.
2. Disconnect UART camera line (or power off camera).
3. Observe serial logs and robot behavior.

Pass criteria:
- Camera timeout warning appears after packet loss.
- If offline persists, robot enters SAFE_STOP.
- No uncontrolled movement while camera is offline.

Fail action:
- Block race runs.
- Verify UART wiring and camera power stability.

## TC-04 Encoder Loss Handling

Goal:
- Verify lockout on persistent encoder failure.

Steps:
1. Start run at low speed.
2. Disconnect one encoder channel (CH1 or CH2).
3. Observe alarms and robot behavior.

Pass criteria:
- Encoder-loss alarm appears.
- Persistent failure triggers SAFE_STOP.
- Motion remains blocked until sensor path is restored.

Fail action:
- Apply rollback procedure from Stage 7.5 in assembly guide.

## TC-05 Lap Counting Stability

Goal:
- Verify robust lap counting without extra increments.

Steps:
1. Run 3 laps in CW direction.
2. Reset and run 3 laps in CCW direction.
3. Compare line-based and gyro-based counters in logs.

Pass criteria:
- Final lap count is exactly 3 in both directions.
- No extra lap jumps.
- Finish transition happens only after valid lap completion.

Fail action:
- Recalibrate line thresholds.
- Recheck cooldown and line-confirm logic.

## TC-06 Recovery Behavior

Goal:
- Verify smooth recovery after short non-critical fault.

Steps:
1. Induce short disturbance (temporary partial view loss or short sensor glitch).
2. Restore normal conditions.
3. Observe steering and speed transition.

Pass criteria:
- Robot recovers control without unsafe jerk.
- No uncommanded acceleration spike.
- Track direction remains consistent.

Fail action:
- Tune PID/damping and verify sensor noise filtering.

## TC-07 Start Procedure Compliance (WRO 9.6-9.14)

Goal:
- Verify start sequence matches official rules.

Steps:
1. Place robot in start zone switched off.
2. Switch on with one power switch.
3. Confirm waiting state before start.
4. On judge-like command, press one start button.

Pass criteria:
- Robot is switched off before placement.
- Exactly one switch is used for power on.
- Exactly one start button triggers motion.
- Motion starts only after start button press.

Fail action:
- Fix startup logic or hardware interface before competition.

## TC-08 Finish Behavior Compliance (WRO 9.24.2 / 9.24.4)

Goal:
- Verify legal end-of-round behavior for both challenges.

Steps:
1. Open Challenge run: complete 3 laps.
2. Obstacle Challenge run: complete 3 laps and parking sequence.
3. Observe finish conditions and robot stop.

Pass criteria:
- Open: after 3 complete laps, robot stops autonomously in finish section.
- Obstacle: after 3 complete laps, robot stops in valid end state (correct section or parking lot).
- No manual touch used to force finish.

Fail action:
- Recheck lap completion logic and finish-state transitions.

## Record for each test

Required fields:
- Date/time
- Firmware version
- Challenge mode (Open/Obstacle)
- Track condition and direction (CW/CCW)
- Battery voltage (start/end)
- Result: PASS/FAIL
- Notes and follow-up action

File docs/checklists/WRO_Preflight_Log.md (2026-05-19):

# WRO Preflight Log (v13)

## Session
- Date:
- Location:
- Firmware: `wro_v13_main.cpp` (target 11)
- `OBSTACLE_MODE`: 0 (Open) / 1 (Obstacle) — circle one
- `HAS_SIDE_TOF`: 0 / 1 — circle one
- Operator:

## Hardware Check
- [ ] Battery voltage in range (LiPo 7.0–8.4 V)
- [ ] Connectors tight (motor power, servo, sensors)
- [ ] No wire damage
- [ ] Wheels / steering move freely
- [ ] VL53L1X sensors powered from 5 V (VIN), not 3.3 V

## I2C Scanner Check (`diag_scan_i2c_v13.cpp`, target 2)
Both buses scanned. Pre-VL53L1X-remap, expected addresses are:
- [ ] **I2C0 (Wire)**: `0x68` (IMU) + `0x36` (AS5600 Left) + `0x29` (VL53L1X Front)
- [ ] **I2C1 (Wire1)**: `0x36` (AS5600 Right) + `0x29` (VL53L1X Side)
- [ ] **No `0x70`** (TCA9548A is gone in v13)

## Encoder Check (`diag_test_encoders.cpp`, target 8)
- [ ] AS5600 Left (I2C0) raw 0–4095, ticks accumulate when wheel turns
- [ ] AS5600 Right (I2C1) raw 0–4095, ticks accumulate when wheel turns
- [ ] No `-1` returns from `as5600_read()`
- [ ] Magnet status reports `OK` for both encoders

## VL53L1X Check (`diag_test_vl53l1x.cpp`, target 9)
- [ ] Front and side sensors come up at remapped addresses (0x30, 0x31)
- [ ] Distances change smoothly when a hand is moved 10–100 cm in front
- [ ] No `9999` saturation reads at normal distances
- [ ] XSHUT pins driven HIGH after boot dance completes

## Bench Test (`diag_bench_test_v13.cpp`, target 10)
- [ ] IMU yaw responds to chassis rotation by hand
- [ ] Servo sweeps left/center/right cleanly via `sl`/`sc`/`sr`
- [ ] Motor PWM ramps forward and reverse via `f`/`b` (wheels off the ground!)
- [ ] Camera frames received over UART2 (live mode `e`)
- [ ] E-Stop button reads correctly (status `s`)

## Safety Check (under target 11)
- [ ] E-Stop press → immediate motor stop (<50 ms)
- [ ] E-Stop release → controlled resume, PIDs reset
- [ ] Camera timeout (Obstacle mode) → `SAFE_STOP` after `CAM_SILENT_STOP_MS` (3 s)
- [ ] Software E-Stop (`!` over USB serial) works
- [ ] Encoder fail-counter trips → `SAFE_STOP` (verify by yanking one I2C bus briefly)

## Servo Calibration (`sketches/servo_calibrate/servo_calibrate.ino`)
- [ ] Center, left, right µs measured on the actual chassis (using the calibration sketch)
- [ ] `SERVO_CENTER_US` / `SERVO_LEFT_US` / `SERVO_RIGHT_US` updated in `wro_hw_config_v13.h`
- [ ] 60 µs safety margin (`SERVO_MARGIN_US`) leaves the servo unstalled at the end-stops

## Final Decision
- [ ] READY FOR TRACK
- [ ] NEED FIXES BEFORE RUN

Notes:

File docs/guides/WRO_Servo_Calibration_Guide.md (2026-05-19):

# WRO Servo Calibration Guide

**Servo:** JX PDI-6221MG
**MCU:** ESP32-S3-DevKitC-1 N8R8 (v13)
**Pin:** GPIO 42
**Firmware:** [`sketches/servo_calibrate/servo_calibrate.ino`](../../sketches/servo_calibrate/servo_calibrate.ino) — standalone Arduino IDE sketch already wired to GPIO 42 with v13 calibration constants.

> The legacy `src/esp32/legacy/legacy_test_servo_calibrate.cpp` (build target 7) was the v11 calibration program on GPIO 27 and is kept as historical reference only. For v13 use the standalone sketch above, which has the same workflow with v13 hardware bindings.

---

## Why calibration matters

When you command the servo to 90° (centre) after it was at 135° (right),
you might notice the wheel doesn't land at *exactly* the same spot it was
when it went to 90° from 45° (left). This is called **hysteresis** and it
has three main causes:

| Cause | What happens | Fix |
|---|---|-----|
| **Gear backlash** | Tiny gaps between gear teeth let the output shaft sit at slightly different positions depending on which direction it arrived from. | Cannot be eliminated, but you can compensate in software. |
| **Linkage play** | Loose ball links, worn servo horn splines, or a long steering rod amplify the backlash. | Tighten or replace ball links. Use a metal servo horn. Minimise linkage length. |
| **Coarse PWM mapping** | `servo.write(90)` converts to 1500 µs, but your servo's true mechanical centre might be 1485 µs or 1520 µs. A 15 µs error is ~1.5° of steering angle. | Calibrate in **microseconds**, not degrees. |

---

## Before you begin — mechanical checks

Do these FIRST. No amount of software calibration fixes bad mechanics.

### 1. Tighten everything

- [ ] Servo horn screw is tight (the screw in the centre of the horn).
- [ ] Servo horn splines have no slop — if they do, replace the horn
      or try a different spline tooth position.
- [ ] Ball links on the steering rod click firmly with no wiggle.
- [ ] Servo is screwed down to the chassis with no flex.
- [ ] Steering rod has no visible bend.

### 2. Set the horn at mechanical centre

1. Power the servo **without** the horn attached.
2. Send 1500 µs (the calibration tool starts there automatically).
3. Now press the horn onto the splines so that the wheels point straight.
4. Tighten the horn screw.

This ensures that the servo's electrical midpoint approximately matches
the mechanical straight-ahead position, reducing the offset you need to
trim later.

---

## Calibration procedure (step by step)

### Step 0: Flash the calibration firmware

Open `sketches/servo_calibrate/servo_calibrate.ino` in the Arduino IDE and upload it as a standalone sketch. Open Serial Monitor at **115200 baud** with "Newline" line ending.

(The sketch is independent of `wro_build_target.h`; it doesn't pull in the rest of the firmware.)

### Step 1: Find true centre

1. The servo starts at 1500 µs.
2. Type **`t`** to enter the interactive trim mode.
3. Look at the front wheels from directly above/ahead.
4. Use **`+`** / **`-`** (±5 µs) to nudge until the wheels are
   *perfectly* straight. Use **`>`** / **`<`** (±50 µs) for big jumps.
5. When satisfied, type **`x`** to save.

> **Tip:** Place a ruler or straight edge against the front wheels to
> judge alignment precisely. Even 1° matters at competition speed.

Write down the value. Example: **1485 µs**.

### Step 2: Find maximum right

1. From centre, press **`>`** repeatedly (or type e.g. `s2000`) to steer
   right until either:
   - The steering linkage hits a mechanical stop, OR
   - The wheel angle reaches ~45° from centre (equivalent to the old
     `SERVO_MAX_RIGHT = 135`).
2. **Do not push past the mechanical stop** — you'll strip the servo gears.
3. Type **`R`** to save this as the right limit.

Write down the value. Example: **1940 µs**.

### Step 3: Find maximum left

Same process in the other direction. Type **`L`** to save.

Write down the value. Example: **1040 µs**.

### Step 4: Measure hysteresis

1. Type **`h`** to run the hysteresis test.
2. This moves the servo right→centre and left→centre, 10 times each.
3. Watch the wheel at each "centre" stop. If it consistently lands
   slightly left when approaching from the right (or vice versa), that's
   your backlash gap.
4. Estimate the gap in µs. Typical for JX PDI-6221MG: **5–15 µs**.

### Step 5: Check repeatability

1. Type **`r`** for 20 full cycles (right → centre → left → centre).
2. The wheel should always return to the same centre position.
   If it drifts over cycles, there's a mechanical issue (horn slipping,
   linkage loosening, servo overheating).

### Step 6: Print and record your values

Type **`p`**. You'll see output like:

```
╔══════════════════════════════════════╗
║    SERVO CALIBRATION SUMMARY         ║
╠══════════════════════════════════════╣
║  Centre:     1485 µs
║  Max right:  1940 µs
║  Max left:   1040 µs
╠══════════════════════════════════════╣
║  Range right: +455 µs from centre
║  Range left:  -445 µs from centre
╠══════════════════════════════════════╣
║  Copy these into wro_hw_config_v13.h:
║
║  #define SERVO_CENTER_US   1485
║  #define SERVO_RIGHT_US    1940
║  #define SERVO_LEFT_US     1040
║
║  Equivalent angles (ESP32Servo):
║  Centre ≈ 88°
║  Right  ≈ 129°
║  Left   ≈ 48°
╚══════════════════════════════════════╝
```

---

## Applying calibration to the main firmware

After calibration, update the µs constants in `src/esp32/wro_hw_config_v13.h` (`SERVO_CENTER_US`, `SERVO_LEFT_US`, `SERVO_RIGHT_US`). The v13 firmware already drives the servo with `writeMicroseconds()` via the `writeSteeringUs()` helper in `wro_v13_main.cpp`, so the only change is updating the three constants and reflashing.

### What to change

**Replace the old degree-based constants:**

```cpp
// OLD — imprecise
#define SERVO_CENTER      90
#define SERVO_MAX_RIGHT   135
#define SERVO_MAX_LEFT    45
```

**With microsecond constants from your calibration:**

```cpp
// NEW — calibrated in µs (run sketches/servo_calibrate, or read from diag_bench_test_v13 target 10)
#define SERVO_CENTER_US    1485   // <- your measured value
#define SERVO_RIGHT_US     1940   // <- your measured value
#define SERVO_LEFT_US      1040   // <- your measured value
```

**Update `setSteering()` to work in microseconds:**

```cpp
void setSteering(int us) {
  us = constrain(us, SERVO_LEFT_US, SERVO_RIGHT_US);
  steeringServo.writeMicroseconds(us);
}
```

**Update every place that writes a steering value.**  
Throughout the code, replace angle calculations with µs calculations.
The simplest approach: keep the rest of the code using a **-100 to +100
abstract steering range** and map it to µs in `setSteering()`:

```cpp
// steerCmd: -100 (full left) ... 0 (centre) ... +100 (full right)
void setSteering(int steerCmd) {
  steerCmd = constrain(steerCmd, -100, 100);
  int us;
  if (steerCmd >= 0)
    us = map(steerCmd, 0, 100, SERVO_CENTER_US, SERVO_RIGHT_US);
  else
    us = map(steerCmd, -100, 0, SERVO_LEFT_US, SERVO_CENTER_US);
  steeringServo.writeMicroseconds(us);
}
```

This decouples the PID output (which uses abstract units) from the
physical servo (which uses calibrated microseconds), so recalibrating
only means changing three `#define` values.

---

## Reducing hysteresis in practice

Even after calibration, some backlash remains. These techniques minimise
its effect during a race:

1. **Overshoot-and-settle**: When returning to centre, briefly command
   a few µs *past* centre in the approach direction, then snap to
   centre. This takes up the gear slack. Adds ~20 ms latency.

2. **Always approach from the same side**: If the servo is at 1700 µs
   (right) and you want centre, move to centre−10 µs first, then to
   centre. This ensures the gears always seat the same way.

3. **Increase servo dead-band tolerance in PID**: If your PID
   oscillates within ±10 µs of the setpoint, it's chasing backlash.
   Add a dead zone: don't update the servo if the new command is within
   ±8 µs of the last written value.

4. **Mechanical**: Replace plastic ball links with metal ones. Use a
   metal servo horn instead of the stock plastic one. Shorter steering
   rod = less amplification of backlash.

---

## Troubleshooting

| Symptom | Likely cause | Action |
|---|---|---|
| Servo jitters at rest | Electrical noise on signal wire, or the servo is fighting a mechanical bind | Add a 100 nF ceramic cap between servo signal and GND, close to the servo connector. Check for linkage binds. |
| Centre drifts over time | Servo horn slipping on splines | Tighten horn screw. Use thread-lock (blue Loctite) on the screw. |
| Loud buzzing at extreme angles | Linkage hitting a hard stop while the servo tries to push further | Reduce `SERVO_RIGHT_US` / `SERVO_LEFT_US` by 20–50 µs to stay inside the mechanical range. |
| Asymmetric range (right > left or vice versa) | Horn installed one spline tooth off centre | Remove horn, re-seat at 1500 µs, re-calibrate. |
| `setSteering()` has no effect | Servo not attached, wrong pin, or timer conflict with motor PWM | Verify `steeringServo.attach(SERVO_PIN, SERVO_LEFT_US, SERVO_RIGHT_US)` is called with `SERVO_PIN = 42` for v13. ESP32Servo and `ledcAttach` can conflict if they use the same timer — servo defaults to timer 0, motor PWM should use other timers. |

---

## Quick reference

| Parameter | Your value | Date measured |
|---|---|---|
| Centre (µs) | _______ | ____/____/____ |
| Max right (µs) | _______ | ____/____/____ |
| Max left (µs) | _______ | ____/____/____ |
| Hysteresis (µs) | _______ | ____/____/____ |
| Horn position | _______ spline tooth | ____/____/____ |
| Linkage rod length (mm) | _______ | ____/____/____ |

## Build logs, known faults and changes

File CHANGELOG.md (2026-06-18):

# CHANGELOG

## Unreleased — Camera backend switch + diagnostics/tuning hardening

### Why
The OpenMV H7 Plus's OV5640 sensor module died 5 days before competition.
Rather than risk a no-camera run, the ESP32 firmware was made
backend-agnostic and a Pixy2/2.1 was wired onto the same UART2 pins as an
interim/active camera.

### Added
- **Pixy2 camera backend** (`src/esp32/wro_camera_pixy2.cpp`, `CAMERA_BACKEND` in `wro_config_v13.h` §12) — binary block-protocol driver feeding the same `g_cam` struct as the OpenMV backend, so FSM/failsafes/telemetry are unchanged. `CAMERA_BACKEND` defaults to `CAMERA_BACKEND_PIXY2`; flip back to `CAMERA_BACKEND_OPENMV` if the OpenMV module is revived.
- `src/espcam/` (ESP32-CAM + Pixy2 vision sketch) and [`docs/guides/WRO_Pixy2_Setup.md`](docs/guides/WRO_Pixy2_Setup.md) — signature teaching order (1=red pillar, 2=green pillar, 3=orange line, 4=blue line, 5=magenta parking) and UART config (115200 baud, factory default is 19200).
- Diagnostic target 12, `src/esp32/diag_test_camera.cpp` (`WRO_TARGET_TEST_CAMERA`) — verifies the active camera backend responds over UART before a test session.
- Encoder diagnostic (target 8, `diag_test_encoders.cpp`) rewritten with a 4-step CONNECTION/MAGNET/STABILITY/ODOMETRY sequence and live keys (`s`, `m`, `z`, `h`) to catch failing AS5600 magnets before they corrupt odometry.
- `wro_steering_comp.h` — live-tunable per-side steering gain trim to correct chassis-specific left/right bias.
- `wro_telemetry_wifi.cpp/.h` — optional softAP + UDP broadcast mirror of telemetry for bench debugging, gated by the `WIFI_TELEMETRY` flag (off by default; must stay off for competition per Rule 11.10, no wireless during the run).

### Changed (sensor/control retunes)
- VL53L1X distance mode: Medium → Long.
- `TURN_COMMIT_MM`: 350 → 420.
- `TURN_BRAKE_MS`: 180 → 100.
- `OPEN_MAX_PWM`: 80 → 65.
- E-Stop button wiring is now a real hardware stop (previously bypassed during bench testing).

## Unreleased — Repo signposting + diagnostic rename

### Added
- README in `src/esp32/`, `src/openmv/`, `sketches/`, `v-photos/`, `t-photos/`, `video/` so a first-time visitor can orient themselves without reading source.
- "For first-time viewers / WRO judges" and "Testing & Calibration Workflow" sections in root `README.md`.

### Renamed
4 v13 diagnostic source files prefixed with `diag_` so they sort together in the Arduino IDE file list and are visually distinct from production firmware. The build-target macros (`WRO_TARGET_SCAN_I2C` = 2, `WRO_TARGET_TEST_ENCODERS` = 8, `WRO_TARGET_TEST_VL53L1X` = 9, `WRO_TARGET_BENCH_TEST` = 10) are unchanged.

| Old path | New path |
|---|---|
| `src/esp32/scan_i2c_v13.cpp` | `src/esp32/diag_scan_i2c_v13.cpp` |
| `src/esp32/test_encoders.cpp` | `src/esp32/diag_test_encoders.cpp` |
| `src/esp32/test_vl53l1x.cpp` | `src/esp32/diag_test_vl53l1x.cpp` |
| `src/esp32/bench_test_v13.cpp` | `src/esp32/diag_bench_test_v13.cpp` |

> Why not move into `src/esp32/diagnostics/`? Arduino IDE doesn't recurse into subfolders (same reason `legacy/` is documented as not auto-compiled in [`src/esp32/legacy/README.md`](src/esp32/legacy/README.md)). A folder move would break the documented preflight workflow.

### Updated
- `src/esp32/esp32.ino`, `wro_build_target.h` — comment-only target tables now reference `diag_*.cpp` filenames.
- `docs/README.md`, `docs/WRO_FE_SKILL.md`, all of `docs/checklists/`, `docs/guides/WRO_Robot_Assembly_and_Startup_Guide.md`, `docs/guides/WRO_Servo_Calibration_Guide.md`, `docs/strategy/WRO_Migration_v12_to_v13.md`, `docs/strategy/WRO_Rule_Compliance_Matrix.md`, `.claude/agents/wro-preflight.md` — diagnostic paths updated to `diag_*.cpp`.
- `schemes/WRO_Full_System_Diagram.png` / `.svg` — regenerated from current v13 `.mmd` source (was last rendered against v12 hardware).

---

## v13.0 — Sensor revert + dual-I2C (May 2026)

### Why
The v12 plan called for AS5048A SPI encoders + TFMini-S UART distance sensors. The parts hadn't arrived in time, and meanwhile the TCA9548A I2C mux on the existing v11 board burned out. Rather than wait, v13 keeps the **new ESP32-S3** main controller from v12 but **reverts the sensor stack to the v11 hardware** (AS5600 + VL53L1X). The address-collision problem the mux used to solve is now handled by:
- **Two native I2C peripherals** on the ESP32-S3 (Wire / Wire1) — one AS5600 per bus.
- **XSHUT-based runtime address remapping** for the VL53L1X pair.

### Breaking changes (vs v12)
- **Encoders:** AS5048A (SPI, 14-bit) → 2× AS5600 (dual I2C, 12-bit)
- **Distance sensors:** TFMini-S (UART, 12 m) → 2× VL53L1X (I2C, ~3 m Medium mode)
- **Pin map:** SPI HSPI freed; I2C1 added on GPIO 11/12; VL53L1X XSHUTs on GPIO 15/16/47
- **Odometry constant:** 1110 ticks/cm → 277 ticks/cm
- **Build target macro:** `WRO_TARGET_V12_MAIN` → `WRO_TARGET_V13_MAIN` (still target 11)

### New files
| File | Purpose |
|---|---|
| `src/esp32/wro_hw_config_v13.h` | Pin map + constants for ESP32-S3 with dual I2C + AS5600 + VL53L1X |
| `src/esp32/wro_config_v13.h` | Algorithm tunables (replaces v12 config) |
| `src/esp32/wro_v13_main.cpp` | Main firmware (replaces wro_v12_main.cpp) |
| `src/esp32/as5600_dual_i2c.h` | AS5600 driver, dual-bus aware |
| `src/esp32/vl53l1x_dual.h` | VL53L1X driver with XSHUT-based addr remap |
| `src/esp32/scan_i2c_v13.cpp` | Two-bus I2C scanner |
| `src/esp32/bench_test_v13.cpp` | Full bench test |
| `src/esp32/test_vl53l1x.cpp` | VL53L1X distance test |
| `docs/guides/WRO_Wiring_Map_v13.md` | Complete v13 wiring reference |
| `docs/strategy/WRO_Migration_v12_to_v13.md` | Step-by-step migration guide |

### Removed files
| File | Replacement |
|---|---|
| `src/esp32/wro_hw_config_v12.h` | `wro_hw_config_v13.h` |
| `src/esp32/wro_config_v12.h` | `wro_config_v13.h` |
| `src/esp32/wro_v12_main.cpp` | `wro_v13_main.cpp` |
| `src/esp32/as5048a_spi.h` | `as5600_dual_i2c.h` |
| `src/esp32/tfmini_s.h` | `vl53l1x_dual.h` |
| `src/esp32/scan_i2c_v12.cpp` | `scan_i2c_v13.cpp` |
| `src/esp32/bench_test_v12.cpp` | `bench_test_v13.cpp` |
| `src/esp32/test_tfmini.cpp` | `test_vl53l1x.cpp` |
| `docs/WRO_Wiring_Map_v12.md` | `WRO_Wiring_Map_v13.md` |
| `docs/WRO_Migration_v11_to_v12.md` | `WRO_Migration_v12_to_v13.md` |

### Updated files
- `src/esp32/wro_build_target.h` — `WRO_TARGET_V13_MAIN` is the new active target; target 9 renamed to `TEST_VL53L1X`
- `src/esp32/wro_odometry.{cpp,h}` — AS5600 12-bit unwrap, dual-bus init via `as5600_init()`
- `src/esp32/wro_sensors.{cpp,h}` — bridges `vl53l1x_dual.h` (same `sens_tf_*` accessor names as v12)
- `src/esp32/wro_imu.cpp` — `Wire.begin(I2C0_SDA, I2C0_SCL)` now uses v13 macros; bus is shared with AS5600 L + VL53L1X F
- `src/esp32/wro_corner.{cpp,h}` — comments updated for VL53L1X; FSM logic unchanged
- `src/esp32/wro_behavior_*.cpp`, `wro_park.cpp`, `wro_race_fsm.cpp`, `wro_estop.cpp`, `wro_telemetry.cpp`, `wro_camera.cpp` — `#include "wro_config_v13.h"` and `WRO_TARGET_V13_MAIN` guard; logic unchanged
- `src/esp32/esp32.ino` — comments updated for v13 target table
- `src/esp32/test_encoders.cpp` — rewritten for AS5600 dual I2C
- `docs/README.md` — reflects v13 file set and workflow
- `README.md` — hardware list updated to v13
- Schemes regenerated for v13 hardware

### Architecture deltas
| Metric | v11 | v12 (planned) | v13 (current) |
|---|-----|---|---|
| MCU | ESP32 DevKitC V4 | ESP32-S3 N8R8 | ESP32-S3 N8R8 |
| Encoders | AS5600 (12-bit, mux) | AS5048A (14-bit, SPI) | AS5600 (12-bit, dual-I2C) |
| Distance | VL53L1X (4 m, mux) | TFMini-S (12 m) | VL53L1X (~3 m) |
| I2C devices | 5 | 1 | 5 (split across 2 buses) |
| I2C buses | 2 (via mux) | 1 | 2 (native peripherals) |
| Mux | TCA9548A | none | none (mux burned, replaced by topology) |

### TODO before competition
- [ ] Bench-test the AS5600 + VL53L1X stack on the actual chassis once parts are mounted
- [ ] Re-measure servo end-stops with target 7 (still pending v13 port; can read µs from target 10 bench output)
- [x] Re-render `schemes/WRO_Full_System_Diagram.png` / `.svg` from the v13 `.mmd` source ✓ (Unreleased section above)
- [ ] Compete

---

## v12.1 — Legacy file rename (May 2026, never fielded)

Renamed v11 source files to `legacy_*.cpp` so the v12 architecture could land cleanly. v12 was never deployed to hardware (parts weren't available); the file structure carried over into v13.

## v12.0 — Hardware Upgrade (May 2026, never fielded)
- **MCU:** ESP32 DevKitC V4 → ESP32-S3-DevKitC-1 N8R8 ✓ (carried into v13)
- **Encoders:** AS5600 (I2C) → AS5048A (SPI) ✗ (parts didn't arrive; v13 reverted)
- **Distance:** VL53L1X (I2C) → TFMini-S (UART) ✗ (parts didn't arrive; v13 reverted)
- TCA9548A I2C mux removed ✓ (carried into v13 — mux burned out anyway)

## v11.0 — Competition Ready (March 2026)
- Dual I2C bus architecture via TCA9548A mux
- Camera UART v3 with XOR checksum
- Parallel parking FSM (APPROACH → ALIGN → CREEP → FINAL)
- Blind turn improvements: WALL_BIT OR pillar dist < 35 cm
- S-curve pre-positioning from FAR pillar when both visible
- Bug fixes: lap counting cooldown, parking alignment delta

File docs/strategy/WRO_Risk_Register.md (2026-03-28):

# WRO Risk Register

| ID | Risk | Impact | Likelihood | Detection | Mitigation | Owner |
|----|---|---|---|---|---|---|
| R1 | Camera frame loss | High | Medium | UART timeout warnings | Cable fixation, protocol validation, safe stop | Vision |
| R2 | I2C noise / dropout | High | Medium | Scanner mismatch, encoder alarms | Short I2C wires, solid GND, retries | Electronics |
| R3 | E-Stop hardware failure | Critical | Low | Preflight E-Stop test fail | Dual checks each run, button replacement policy | Safety |
| R4 | IMU drift | Medium | Medium | Wrong lap increments | Recalibration, vibration isolation, dt clamp | Controls |
| R5 | Wheel slip at high speed | High | Medium | Unstable line following | Speed ramping, turn speed limits, tire setup | Mechanics |
| R6 | Brownout under load | High | Medium | Random resets | Battery health checks, power distribution improvements | Electronics |
| R7 | Connector loosening | Medium | Medium | Intermittent failures | Strain relief, locking connectors, preflight inspection | Hardware |

## Update rule
- Review before every competition session.
- Add new risks discovered in testing.
- Track mitigation status weekly.

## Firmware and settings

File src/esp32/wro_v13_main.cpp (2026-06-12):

#include "wro_build_target.h"
#if WRO_ACTIVE_TARGET == WRO_TARGET_V13_MAIN

/*
 * WRO Future Engineers — v13 Main Firmware
 *
 * Hardware: ESP32-S3-DevKitC-1 N8R8 + 2× AS5600 (dual I2C) +
 *           VL53L1X front + side (XSHUT remap) + ICM-20948 IMU (I2C0) +
 *           OpenMV H7 Plus (UART2) + BTS7960 motor + JX PDI-6221MG servo.
 *
 * v13 keeps the v12 architecture intact — only the bottom HAL layer changed.
 * The TCA9548A I2C mux is GONE (it burned out); two AS5600s now sit on the
 * ESP32-S3's two native I2C peripherals (Wire and Wire1), and the VL53L1X
 * pair uses XSHUT-based address remapping at boot.
 *
 * Layered architecture (top-down only):
 *   HAL: drivers (as5600_dual_i2c.h, vl53l1x_dual.h, ICM20948 lib)
 *   Estimation: wro_imu, wro_odometry, wro_camera
 *   Behavior: wro_corner, wro_behavior_open, wro_behavior_obstacle, wro_park
 *   Control: this file (steering_mixer + speed_ramp)
 *   FSM: wro_race_fsm + wro_estop (parallel)
 *
 * Mode is a single compile-time #define in wro_config_v13.h:
 *   OBSTACLE_MODE 0 = Open Challenge   (3 laps, walls only)
 *   OBSTACLE_MODE 1 = Obstacle Challenge (red/green pillars + parking)
 * (Rule 9.9 compliance: NO physical mode switches.)
 *
 * Team Faith | WRO Future Engineers 2026 | v13.0
 */

#include <Arduino.h>
#include <WiFi.h>
#include <esp_bt.h>
#include <esp_task_wdt.h>

#include "wro_config_v13.h"
#include "wro_i2c_buses.h"
#include "wro_imu.h"
#include "wro_odometry.h"
#include "wro_camera.h"
#include "wro_corner.h"
#include "wro_behavior_open.h"
#include "wro_behavior_obstacle.h"
#include "wro_park.h"
#include "wro_estop.h"
#include "wro_telemetry.h"
#include "wro_telemetry_wifi.h"
#include "wro_race_fsm.h"
#include "wro_sensors.h"
#include "wro_steering_comp.h"

static int  commandSpeed = 0;        // ramped actual PWM (signed)
static unsigned long lastLoopMs = 0;

// ─── Servo write with calibrated µs ───────────────────────────
static void writeSteeringUs(int us) {
  // Asymmetry trim must run BEFORE the safe clamp so a gain >1 can never
  // push the horn past the mechanical end-stop.
  us = steer_compensate_us(us, g_steer_gain_left, g_steer_gain_right);
  if (us > SERVO_RIGHT_SAFE_US) us = SERVO_RIGHT_SAFE_US;
  if (us < SERVO_LEFT_SAFE_US)  us = SERVO_LEFT_SAFE_US;
  
  // Convert µs to 14-bit duty cycle for 50Hz PWM (20000 µs period)
  // duty = (us * 16384) / 20000
  uint32_t duty = (us * 16384) / 20000;
  ledcWrite(SERVO_PIN, duty);
}

// ─── Motor: BTS7960 LEDC PWM, signed speed ────────────────────
static void writeMotor(int signedPwm) {
  if (signedPwm >  255) signedPwm =  255;
  if (signedPwm < -255) signedPwm = -255;
  int mag = abs(signedPwm);
  if (mag != 0 && mag < MIN_DRIVE_PWM) mag = MIN_DRIVE_PWM;     // deadband floor

  if (signedPwm > 0) {
    ledcWrite(MOTOR_L_PWM, 0);
    ledcWrite(MOTOR_R_PWM, mag);
  } else if (signedPwm < 0) {
    ledcWrite(MOTOR_R_PWM, 0);
    ledcWrite(MOTOR_L_PWM, mag);
  } else {
    ledcWrite(MOTOR_R_PWM, 0);
    ledcWrite(MOTOR_L_PWM, 0);
  }
}

// ─── Speed ramp: avoid torque spikes / wheel slip ─────────────
static void applySpeedRamp(int target) {
  if (commandSpeed < target) commandSpeed = min(commandSpeed + SPEED_RAMP_STEP, target);
  else if (commandSpeed > target) commandSpeed = max(commandSpeed - SPEED_RAMP_STEP, target);
  writeMotor(commandSpeed);
}

void setup() {
  // ─── Rule 11.10: kill all wireless before anything else ────
  WiFi.mode(WIFI_OFF);
  btStop();

  Serial.begin(115200);
  delay(200);
  Serial.println();
  Serial.println("============================================================");
  Serial.println(" WRO FE 2026 — Team Faith — v13.0 main firmware");
  Serial.print  (" Mode: ");
#if OBSTACLE_MODE == 1
  Serial.println("OBSTACLE CHALLENGE");
#else
  Serial.println("OPEN CHALLENGE");
#endif
#if WIFI_TELEMETRY
  Serial.println(" WiFi: TELEMETRY AP ON - TESTING BUILD, set WIFI_TELEMETRY 0 for competition (Rule 11.10)");
#else
  Serial.println(" WiFi: OFF, BT: OFF (Rule 11.10)");
#endif
  Serial.println("============================================================");

  // ─── E-Stop input (early so any held-button bug is grace-windowed) ──
  estop_init();

  // ─── Status LED ─────────────────────────────────────────────
  pinMode(LED_PIN, OUTPUT);
  digitalWrite(LED_PIN, LOW);

  // ─── Steering servo ─────────────────────────────────────────
  ledcAttach(SERVO_PIN, 50, 14);       // 50 Hz, 14-bit resolution
  writeSteeringUs(SERVO_CENTER_US);

  // ─── Motor driver pins ──────────────────────────────────────
  pinMode(MOTOR_R_EN, OUTPUT);
  pinMode(MOTOR_L_EN, OUTPUT);
  digitalWrite(MOTOR_R_EN, HIGH);
  digitalWrite(MOTOR_L_EN, HIGH);
  
  ledcAttach(MOTOR_R_PWM, 20000, 8);   // 20 kHz, 8-bit (0..255)
  ledcAttach(MOTOR_L_PWM, 20000, 8);
  ledcWrite(MOTOR_R_PWM, 0);
  ledcWrite(MOTOR_L_PWM, 0);

  // ─── I2C buses (Wire + Wire1) ───────────────────────────────
  i2c_buses_init();

  // ─── Encoders (AS5600 dual I2C) ─────────────────────────────
  if (!odo_init()) {
    Serial.println("ERROR: AS5600 init failed (check both I2C buses + magnet air-gap 0.5-3 mm)");
  } else {
    Serial.println("AS5600 dual I2C: OK");
  }

  // ─── VL53L1X distance sensors (owned by wro_sensors) ───────
  sens_init();

  // ─── Camera (UART2) ─────────────────────────────────────────
  cam_init();

  // ─── IMU + gyro calibration ─────────────────────────────────
  if (!imu_init()) {
    Serial.println("ERROR: ICM-20948 not found! Halting.");
    while (1) {
      digitalWrite(LED_PIN, HIGH); delay(100);
      digitalWrite(LED_PIN, LOW);  delay(100);
      esp_task_wdt_reset();           // no-op until WDT armed below; keeps blink-of-death reboot-free
    }
  } else {
    Serial.println("ICM-20948 IMU: OK");
  }
  // Gyro bias calibration. A failed calibration leaves bias = 0, which means
  // 30–120°/min of yaw drift — retry before giving up, and be loud if it
  // still fails.
  {
    bool gyroCalOk = false;
    for (int attempt = 1; attempt <= 3 && !gyroCalOk; attempt++) {
      gyroCalOk = imu_calibrate_gyro();
      if (!gyroCalOk) {
        Serial.printf("WARN: gyro calibration weak (attempt %d/3) - retrying; keep the robot STILL\n", attempt);
      }
    }
    if (!gyroCalOk) {
      Serial.println("WARN: gyro calibration FAILED after 3 attempts - yaw will drift!");
      Serial.println("WARN: power-cycle on a still surface before racing.");
    }
  }

  // ─── Algorithm modules ──────────────────────────────────────
  open_init();
  obs_init();
  park_init();
  corner_init();
  tlm_init();
  race_init();

  // Wi-Fi telemetry mirror (testing builds only; no-op when WIFI_TELEMETRY=0).
  // Must run before the WDT below: softAP() blocks longer than WDT_TIMEOUT_MS.
  tlm_wifi_init();

  // Arm task watchdog last — once registered, every loop iteration must
  // call esp_task_wdt_reset() within WDT_TIMEOUT_MS or the board hard-resets.
  // Done after gyro calibration (which uses delay() and would tickle the WDT).
  // reconfigure() works when the Arduino core pre-initialized the TWDT
  // (the default); fall back to init() for cores built without it. Either
  // way, VERIFY the result — printing "armed" while arming silently failed
  // would leave the race loop with no hang protection.
  esp_task_wdt_config_t wdt_cfg = {
      .timeout_ms    = WDT_TIMEOUT_MS,
      .idle_core_mask = 0,
      .trigger_panic = true,
  };
  esp_err_t wdtErr = esp_task_wdt_reconfigure(&wdt_cfg);
  if (wdtErr != ESP_OK) wdtErr = esp_task_wdt_init(&wdt_cfg);   // TWDT not pre-inited by this core
  esp_err_t wdtAddErr = esp_task_wdt_add(NULL);
  if (wdtErr != ESP_OK || wdtAddErr != ESP_OK) {
    Serial.printf("ERROR: task watchdog arming FAILED (cfg=%d add=%d) - NO hang protection!\n",
                  (int)wdtErr, (int)wdtAddErr);
  } else {
    Serial.print("Task watchdog armed at ");
    Serial.print(WDT_TIMEOUT_MS);
    Serial.println(" ms");
  }

  Serial.println("System ready. Press E-Stop to start.");
  digitalWrite(LED_PIN, HIGH);
  lastLoopMs = millis();
}

void loop() {
  unsigned long now = millis();
  if (now - lastLoopMs < (unsigned long)LOOP_INTERVAL_MS) return;
  lastLoopMs = now;

  // Pet the watchdog at the top of every active tick. If any blocking
  // call below stalls (I2C lock-up, library timeout) for >WDT_TIMEOUT_MS
  // (200 ms), the ESP32 reboots rather than sit motionless on the track.
  esp_task_wdt_reset();

  // ─── Sensor updates (HAL → estimation) ─────────────────────
  imu_update();
  odo_update();
  sens_update();
  cam_update();
  estop_update();

  // ─── Top-level FSM produces commands ───────────────────────
  race_update();

  // ─── Apply commands to actuators ───────────────────────────
  writeSteeringUs(g_cmd_steer_us);
  // SAFE_STOP must cut drive immediately, not coast down through the ramp
  // (estop.h contract: "motor off immediately, NOT through ramp").
  if (g_race_state == RS_SAFE_STOP) {
    commandSpeed = 0;
    writeMotor(0);
  } else {
    applySpeedRamp(g_cmd_speed_pwm);
  }

  // ─── Telemetry (rate-limited internally) ───────────────────
  tlm_update_periodic(g_race_state, g_corner_state, g_lap_count,
                      commandSpeed, g_cmd_steer_us);

  // ─── Pet the dog ───────────────────────────────────────────
  esp_task_wdt_reset();
}

#endif  // WRO_ACTIVE_TARGET == WRO_TARGET_V13_MAIN

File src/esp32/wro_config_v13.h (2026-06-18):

#pragma once
/*
 * WRO Future Engineers v13 — Algorithm Tunables
 *
 * Pin map and hardware constants live in wro_hw_config_v13.h.
 * This file holds only behavior gains, thresholds, and the
 * compile-time challenge mode flag (Rule 9.9: no physical switches).
 *
 * v13 = v12 architecture (FSM + behaviors unchanged) but rewired for the
 * original v11 sensor stack: AS5600 (dual I2C) + VL53L1X (XSHUT remap).
 *
 * Team Faith | WRO Future Engineers 2026 | v13.0
 */

#include "wro_hw_config_v13.h"

// ============================================================
// 0.  CHALLENGE MODE — the ONLY compile-time flag (Rule 9.9)
// ============================================================
//   0 = Open Challenge     (no pillars, just walls + 3 laps)
//   1 = Obstacle Challenge (red/green pillars + parking)
#define OBSTACLE_MODE  0

// Side VL53L1X is wired by default in v13 (the sensor exists; mux issues are
// gone). Set to 0 only if you physically disconnect the side sensor.
#define HAS_SIDE_TOF   1

// ============================================================
// 0b. DEFAULT RACE DIRECTION (fallback until the camera confirms)
// ============================================================
//   -1 = CCW (robot drives LEFT from start / counter-clockwise loop)
//   +1 = CW  (robot drives RIGHT from start / clockwise loop)
//   The camera locks the true direction from the orange/blue line within the
//   first few frames; this value is only used until then (e.g. before the
//   first colored line is visible). SET IT to match your known start
//   orientation so that if a corner is reached before direction is confirmed,
//   the robot still turns the right way. The firmware prints a one-shot
//   "UNCONFIRMED direction" warning over USB if that ever happens.
#define DEFAULT_RACE_DIRECTION  (-1)

// ============================================================
// 1.  CORNERING — VL53L1X-front + IMU yaw delta state machine
// ============================================================
#define TURN_SLOWDOWN_MM      600    // begin pre-corner slowdown
// 2026-06-11 run log: matte-black wall first returns valid frames around
// 400-450 mm (flickering with 9999 before that). Waiting down to 350 left
// EXECUTE starting at ~175 mm -> TURN_PANIC abort. Commit on first stable
// sighting instead.
// 2026-06-13 run log: commit at 420 left EXECUTE starting ~350-400 mm; the car
// ran out of room and tripped TURN_PANIC (80 mm) after only ~30 deg of the 80
// deg turn -> CN_FAIL/SAFE_STOP. Commit ~120 mm earlier (front DOES see the
// wall at 600-650 mm intermittently) to buy turning room.
#define TURN_COMMIT_MM        500    // commit to turning
#define TURN_FRAMES_DEBOUNCE  3      // valid frames before commit
#define TURN_BRAKE_MS         100    // brake-straight phase (180 ms ate ~14 cm at 0.8 m/s)
#define TURN_SPEED_PWM        50     // PWM during SLOWDOWN/EXECUTE. MUST stay < OPEN_MAX_PWM
                                     // or the "slowdown" SPEEDS THE CAR UP: 2026-06-13 had
                                     // TURN_SPEED_PWM 70 > OPEN_MAX_PWM 65, so the car
                                     // accelerated into the turn and hit the wall.
#define TURN_TARGET_DEG       80.0f  // exit angle (under-rotated; heading-hold cleans last 10°)
#define TURN_MAX_MS           2500   // failsafe abort
#define TURN_LOCKOUT_MS       800    // suppress re-detect after exit
#define TURN_PANIC_MM         100    // hard SAFE_STOP if wall this close in EXECUTE

// 3-point ("saw") turn. 2026-06-13: the front VL53L1X cannot see the matte-
// black wall until ~400 mm, and the car's full-lock turn radius is ~55 cm
// (steering only ~14 deg), so an 80 deg corner can't be cleared in one forward
// arc from there — it stalled at ~27 deg and tripped TURN_PANIC -> CN_FAIL.
// Instead of aborting, reverse a leg (counter-steered so yaw keeps rotating the
// same way), back off the wall, and resume the forward arc. Repeat up to
// TURN_BACK_MAX_TRIES. Set TURN_BACKUP_ENABLE 0 to revert to abort-on-panic.
#define TURN_BACKUP_ENABLE    1
#define TURN_BACK_TRIGGER_MM  200    // wall this close in EXECUTE → reverse leg (must be > TURN_PANIC_MM)
#define TURN_BACK_CLEAR_MM    320    // reverse until the wall is at least this far again
#define TURN_BACK_MAX_MS      700    // time cap on a single reverse leg
#define TURN_BACK_MAX_TRIES   5      // give up (CN_FAIL) after this many reverse legs
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

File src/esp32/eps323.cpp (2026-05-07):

#include "wro_build_target.h"

#if WRO_ACTIVE_TARGET == WRO_TARGET_EPS323

/*
 * WRO Future Engineers — ESP32 Control Firmware
 * Version 11.0 — COMPETITION READY
 *
 * Hardware: ESP32 DevKitC V4, BTS7960 43A (brushed DC 380),
 *           JX PDI-6221MG servo, ICM-20948 IMU,
 *           2x AS5600 encoders (две независимые I2C шины),
 *           OpenMV H7 Plus (UART2).
 *
 * I2C ARCHITECTURE (v11.1 — без PCA9548A):
 *   Bus 1 (Wire,  GPIO21/22): IMU 0x68, AS5600 left 0x36
 *   Bus 2 (Wire1, GPIO25/26): AS5600 right 0x36
 *
 * IMPLEMENTED FEATURES (v11.0):
 *  1.  Camera UART protocol v3 with XOR checksum validation:
 *        RedX,RedDist,GreenX,GreenDist,ModeFlag,ExtraTag*CS
 *  2.  FSM: INIT / TRACKING / BLIND_TURN / PARKING / SAFE_STOP / FINISH
 *  3.  Priority order in updateControl(): BLIND_TURN (camera-independent)
 *        → camera offline (gyro heading) → tracking (pillar/heading PID)
 *  4.  Blind-turn entry: WALL_BIT OR RedDist<35 OR GreenDist<35
 *        (3 consecutive frames) AND directionConfirmed
 *  5.  Dual-pillar PID avoidance with EMA-filtered derivative and
 *        integral reset on pillar-color switch. S-curve pre-positioning
 *        from the FAR pillar when BOTH are visible.
 *  6.  Gyroscope heading hold when no landmarks are visible.
 *  7.  (ToF отключён — нет VL53 в прошивке.)
 *  8.  Parallel parking FSM (APPROACH → ALIGN → CREEP (reverse) → FINAL).
 *  9.  Odometry: AS5600 4096 ticks/rev, D=47mm → 277 ticks/cm,
 *        with wrap-around handling and 50-error safe-stop guard.
 * 10.  Dual lap counting: camera line (orange/blue) + gyroscope 360°.
 * 11.  E-Stop button: press+release = START; during race = SAFE_STOP / resume.
 * 12.  Live PID tuning over USB Serial: P/I/D/G commands.
 * 13.  Adaptive speed profiles Open vs. Obstacle (set at compile time).
 * 14.  Smooth acceleration ramp (SPEED_RAMP_STEP per 10 ms cycle).
 * 15.  Telemetry frame every 200 ms.
 *
 * FIXED BUGS (v10 → v11):
 *  - closeWallCount now ignites on WALL_BIT OR pillar distance < 35 cm
 *    (was only WALL_BIT).
 *  - S-curve for simultaneous pillars now adds a lateral offset from the
 *    FAR pillar so the robot starts to pre-position early.
 *  - Parking ALIGN: выравнивание только по гироскопу (без ToF).
 *  - Parking CREEP now reverses (negative speed) per competition technique.
 *  - Servo pin fixed to GPIO27 (matches WRO_Wiring_Map.md).
 *  - lineConfirmCount is explicitly reset while the cooldown window is
 *    active, preventing false extra laps.
 *  - safeStop() resets lastActivePillar and currentState consistently.
 *  - Blind turn trigger evaluated BEFORE any camera dependence.
 *
 * WRO Rule 9.9: NO physical mode switches. Select mode at compile time
 *               via #define OBSTACLE_CHALLENGE_MODE below.
 */

// ============================================================
// 2.  INCLUDES
// ============================================================
#include <Adafruit_ICM20948.h>
#include <Adafruit_Sensor.h>
#include <ESP32Servo.h>
#include <Wire.h>
#include <math.h>

// ============================================================
// 3.  PINS  (do not change — hardware-defined)
// ============================================================
#define I2C_SDA      21    // Bus 1 (Wire)  — левый AS5600 + IMU
#define I2C_SCL      22
#define I2C_SDA2     25    // Bus 2 (Wire1) — правый AS5600
#define I2C_SCL2     26
#define SERVO_PIN    27    // Steering servo PWM (per WRO_Wiring_Map.md)
#define MOTOR_R_EN   19    // BTS7960 right-enable
#define MOTOR_L_EN   23    // BTS7960 left-enable
#define MOTOR_R_PWM  5     // BTS7960 R-PWM (forward channel)
#define MOTOR_L_PWM  14    // BTS7960 L-PWM (reverse channel)
#define UART_RX      16    // from OpenMV TX
#define UART_TX      17    // to OpenMV RX
#define ESTOP_PIN    32    // E-Stop / Start button, INPUT_PULLUP, active LOW
#define LED_PIN      2     // Status LED

// ============================================================
// 4.  RACE MODE (WRO Rule 9.9 — set at compile time, NOT by a switch)
// ============================================================
// Uncomment for OBSTACLE Challenge (laps + pillars + parking).
// Comment  for OPEN     Challenge (laps only, no pillars/no parking).
// #define OBSTACLE_CHALLENGE_MODE   // <-- Open Challenge активен (CCW, tails-tails)

// ============================================================
// 5.  SERVO AND SPEEDS
// ============================================================
// Calibrated pulse widths in microseconds.
// Run test_servo_calibrate.cpp to find your exact values.
// Center: 1565, Limits: 1215 and 1915 (+/- 350µs).
#define SERVO_CENTER_US    1565  // µs — wheels perfectly straight
#define SERVO_RIGHT_US     1915  // µs — max right steering
#define SERVO_LEFT_US      1215  // µs — max left steering

// Safety margin away from the mechanical end-stops.
// If the servo "knocks/buzzes" at the ends, increase this value (e.g. 80–120).
#define SERVO_MARGIN_US      60
#define SERVO_RIGHT_SAFE_US  (SERVO_RIGHT_US - SERVO_MARGIN_US)
#define SERVO_LEFT_SAFE_US   (SERVO_LEFT_US  + SERVO_MARGIN_US)

// Legacy degree aliases — used throughout updateControl() calculations.
// These are mapped to µs inside setSteering().
#define SERVO_CENTER      90
#define SERVO_MAX_RIGHT   135
#define SERVO_MAX_LEFT    45

// Open Challenge speed profile: gentle, careful drive.
#define OPEN_MAX_SPEED    80    // PWM, 0..255 — обычная езда
#define OPEN_TURN_FAST    70
#define OPEN_TURN_SLOW    55
#define OPEN_MIN_SPEED    40    // Motor deadband compensation floor

// Obstacle Challenge speed profile (favours precision — tighter avoidance).
#define OBS_MAX_SPEED     140
#define OBS_TURN_FAST     110
#define OBS_TURN_SLOW     75
#define OBS_MIN_SPEED     35

// Active values (selected in setup() from the profile above).
int MOTOR_MAX_SPEED = OBS_MAX_SPEED;
int MOTOR_TURN_FAST = OBS_TURN_FAST;
int MOTOR_TURN_SLOW = OBS_TURN_SLOW;
int MOTOR_MIN_SPEED = OBS_MIN_SPEED;

// ============================================================
// 6.  PID COEFFICIENTS AND STATE
// ============================================================
// Pillar-avoidance PID (tunable over Serial: P/I/D commands).
float PID_KP  = 0.35f;   // proportional  — main steering force (уменьшено)
float PID_KI  = 0.001f;  // integral      — corrects steady-state bias (уменьшено)
float PID_KD  = 0.25f;   // derivative    — damps overshoot (EMA-filtered) (увеличено для плавности)
float GYRO_KP = 1.00f;   // heading-hold gain when no camera cue is present

float integralError      = 0.0f;
float filteredDerivative = 0.0f;
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

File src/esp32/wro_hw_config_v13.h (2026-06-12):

#pragma once
/*
 * WRO Future Engineers — Hardware Configuration v13
 * ESP32-S3-DevKitC-1 (N8R8) + 2× AS5600 (dual I2C) + 2× VL53L1X (XSHUT addr-remap)
 *
 * What's different from v12:
 *   v12 used AS5048A SPI encoders + TFMini-S UART distance.
 *   v13 reverts to the original v11 sensor stack (AS5600 I2C + VL53L1X I2C)
 *   while keeping the v12 ESP32-S3 main controller (the TCA9548A mux that
 *   v11 used to share one I2C bus is gone — it burned out in service).
 *
 * How the I2C address conflicts are resolved without a mux:
 *   - 2× AS5600 collide on 0x36 → split across the ESP32-S3's two native
 *     I2C peripherals (Wire = I2C0, Wire1 = I2C1). One AS5600 per bus.
 *   - 2× VL53L1X collide on 0x29 → addresses are remapped at boot via
 *     XSHUT pins (only one VL53L1X per bus enabled at a time, gets a new
 *     address, then the next is enabled). VL53L1X address is RAM-only,
 *     so the sequence is repeated every reset.
 *
 * Bus topology:
 *   I2C0 (Wire,  GPIO 8/9):    ICM-20948 (0x68) + AS5600 Left (0x36) +
 *                              VL53L1X Front (0x29 → 0x30)
 *   I2C1 (Wire1, GPIO 3/4):    AS5600 Right (0x36) +
 *                              VL53L1X Side  (0x29 → 0x31)
 *   UART0 (native USB-C):      Debug / telemetry
 *   UART2 (GPIO 17/18):        OpenMV H7 Plus camera
 *
 * Team Faith | WRO Future Engineers 2026 | v13.0
 */

// ============================================================
//  1.  I2C — bus 0 (Wire) and bus 1 (Wire1)
// ============================================================
#define I2C0_SDA            8
#define I2C0_SCL            9
#define I2C1_SDA            3     // moved from GPIO11 (2026-06). NOTE: GPIO3 is an
                                  // ESP32-S3 strapping pin (JTAG sel) — fine for I2C
                                  // in practice; if boot ever misbehaves, use GPIO13.
#define I2C1_SCL            4     // moved from GPIO12
#define I2C_FREQ_HZ         400000

#define ICM20948_ADDRESS    0x68    // I2C0, AD0 → GND
#define AS5600_ADDRESS      0x36    // both encoders, on different buses

// ============================================================
//  2.  VL53L1X — XSHUT pins (active LOW = sensor in reset)
// ============================================================
//   Each VL53L1X powers up at default address 0x29. We hold all sensors
//   in reset, then bring them up one by one and reassign each to a unique
//   address. Addresses below are runtime targets after the boot dance.
#define VL53L1X_FRONT_XSHUT   15      // I2C0
#define VL53L1X_SIDE_XSHUT    16      // I2C1
#define VL53L1X_THIRD_XSHUT   47      // reserved for optional 3rd sensor (I2C0)

#define VL53L1X_DEFAULT_ADDR  0x29
#define VL53L1X_FRONT_ADDR    0x30
#define VL53L1X_SIDE_ADDR     0x31
#define VL53L1X_THIRD_ADDR    0x32

// ============================================================
//  3.  UART2 — OpenMV Camera (UART0 stays on USB-C debug)
// ============================================================
#define CAMERA_RX           17
#define CAMERA_TX           18
#define CAMERA_BAUD         115200

// ============================================================
//  4.  Motor driver — BTS7960
// ============================================================
#define MOTOR_R_EN          38
#define MOTOR_L_EN          39
#define MOTOR_R_PWM         40    // LEDC Ch0 → forward
#define MOTOR_L_PWM         41    // LEDC Ch1 → reverse

// ============================================================
//  5.  Steering servo
// ============================================================
#define SERVO_PIN           42

// ============================================================
//  6.  E-Stop + LEDs
// ============================================================
#define ESTOP_PIN           21
#define LED_PIN             2
#define RGB_LED_PIN         48

// ============================================================
//  7.  Servo calibration (degrees + microseconds)
// ============================================================
#define SERVO_CENTER        90
#define SERVO_MAX_RIGHT     135
#define SERVO_MAX_LEFT      45
// 2026-06-11 bench recal (servo-cal target): travel is now symmetric,
// 350 µs each side. The old LEFT=1050 under-used the left lock by 50 µs —
// part of the "turns weaker one way" complaint, on top of corner weights.
#define SERVO_CENTER_US     1350
#define SERVO_LEFT_US       1000
#define SERVO_RIGHT_US      1700
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

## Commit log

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2026-04-28 Hardware calibration: updated servo center/limits, ESP32 V3 PWM migration, and OpenMV UART stability fixes
    [HSP94182_assembly.step, WRO_Test_Log.csv, antenna_mount.step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]
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2026-05-07 v12 main firmware: clean-slate rewrite for ESP32-S3 (target 11)
    The v11 firmware (eps323.cpp) failed to corner reliably because the
    turn trigger required a combination of camera + wall + direction
    gates, and the turn exit relied on encoder distance during a slipping
    turn. This rewrite owns cornering with TFMini-S front + IMU yaw delta
    only; encoders are telemetry-only during turns. Camera is never an
    exit condition.
    Architecture (HAL → Estimation → Behavior → Control → FSM):
    - wro_config_v12.h tunables + OBSTACLE_MODE compile flag (Rule 9.9)
    - wro_pid.h generic PID with anti-windup + EMA derivative
    - wro_imu.h/.cpp gyro Z + bias calibration (no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
    [esp32.ino, wro_behavior_obstacle.cpp, wro_behavior_open.cpp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]
2026-05-07 Rename v11 legacy files to legacy_*.cpp; fix scanerI2C typo
    Reflects which files belong to the active v12 firmware versus the
    v11 reference kept for posterity. No behavior change.
    File renames:
    - eps323.cpp → legacy_eps323.cpp
    - test_motor_servo_drive.cpp → legacy_test_motor_servo_drive.cpp
    - test_no_sensors.cpp → legacy_test_no_sensors.cpp
    - test_servo.cpp → legacy_test_servo.cpp
    - test_servo_calibrate.cpp → legacy_test_servo_calibrate.cpp
    - test_short_sequence.cpp → legacy_test_short_sequence.cpp
    - scanerI2C.cpp → scan_i2c_v12.cpp (typo fix; was v12 already)
    Doc updates:
    - README.md: corrected setup step to point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
    [esp32.ino, legacy_eps323.cpp, legacy_test_motor_servo_drive.cpp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]
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2026-05-08 v13: ESP32-S3 + 2× AS5600 dual-I2C + 2× VL53L1X (XSHUT addr-remap)
    Why
    The v12 plan called for AS5048A SPI encoders + TFMini-S UART distance
    sensors. The new parts didn't arrive in time, and meanwhile the v11
    TCA9548A I2C mux burned out. v13 keeps the new ESP32-S3 main controller
    from v12 but reverts the sensor stack to the v11 hardware (AS5600 +
    VL53L1X). The address-collision problem the mux used to solve is now
    handled by:
    - Two native I2C peripherals on the ESP32-S3 (Wire / Wire1) — one
    AS5600 per bus, sidesteps the fixed 0x36 collision.
    - XSHUT-based runtime address remapping for the VL53L1X pair (boot dance
    in vl53l1x_dual.h: hold all in reset, bring up one at a time, write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
    [esp32.ino, vl53l1x_dual.h, wro_behavior_obstacle.cpp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]
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2026-05-09 Clean up obsolete files and add .gitignore
    Removed (24 MB total):
    - HSP94182_3D/cad.zip -- exact duplicate of HSP94182_3D/cad/, plus
    bundled __MACOSX/ metadata pollution
    - .DS_Store -- macOS Finder metadata, never useful in git
    - setup_repo.sh -- one-shot v11 bootstrap that mv'd files into src/.
    Files have lived in src/ for months; running it now would error or
    rearrange working code
    - docs/WRO_All_Code_Combined_2026-03-28.txt (47 KB) -- snapshot of v8.7
    v11 firmware (Russian comments, TCA9548A + AS5600/VL53L1X via mux,
    pre-v12). Authoritative source is src/.
    - docs/WRO_FE_Complete_Project_2026.txt (113 KB) -- same stale v8.7 v11
    snapshot, larger
    Kept on purpose:
    - HSP94182_3D/c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
2026-05-09 OpenMV vision v3.1: rule-grounded calibration, drop vision wall detection
    Rewrote src/openmv/openmv_main.py against the WRO 2026 FE rule book so
    the camera pipeline starts from real specs instead of guessed constants:
    - Distance now uses blob.h() and the rule-fixed pillar height (10 cm,
    rule 13.19) via a clean pinhole model: d = FOCAL_PIX * h_cm / h_px.
    Replaces the magic FOCAL_CONST = 2000 (width-based, ~3x off).
    - New camera-intrinsics block with an explicit on-chassis calibration
    recipe; default FOCAL_PIX = 120 fits the stock 2.8 mm lens at QQVGA.
    - LAB thresholds re-derived from the rule-given RGB values
    (rules 13.21 / 13.22 / 13.27 / 13.9) instead of eyeballed ranges.
    - ROI_LIN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
    [openmv_main.py]
2026-05-09 v13 firmware: fix corner-exit heading snap, direction-aware wall PID, dir debounce, WDT
    Four fixes uncovered by the v13 firmware review:
    1) Corner-exit heading snap was silently dropped (wro_corner.cpp).
    The CN_EXECUTE handler set g_corner_just_exited=true and then called
    enter(CN_EXIT, now). enter() unconditionally writes the flag back to
    false as part of its housekeeping, so race_fsm never observed the exit
    edge and never snapped open_set_target_heading() / obs_set_target_heading()
    to the new quadrant. Effect on the track: after corner #1 the heading
    PID would steer the robot back toward its starting orientation —
    straight into the inner wall on lap 1. Fix: enter()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
    [wro_behavior_open.cpp, wro_config_v13.h, wro_corner.cpp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]
2026-05-10 v13: add task watchdog, fix lap counter, clean up wall-bit doc drift
    Three software-only fixes surfaced by a multi-agent code review of v13.
    Hardware is not yet on the chassis, so these are low-risk pre-integration
    cleanups.
    - ESP32-S3 task watchdog (200 ms) armed at the end of setup() and reset
    every loop tick. Prevents an I2C hang or stuck UART read from silently
    hard-resetting the board mid-race. Uses the ESP-IDF v5.x API
    (esp_task_wdt_reconfigure) which matches Arduino-ESP32 v3.x for the
    ESP32-S3-DevKitC-1 native USB build.
    - Lap counter now uses g_yaw_total * globalDirection instead of fabsf(),
    with a monotonic lastIlaps so a brief back-spin then forward return
    cannot re-c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
    [wro_config_v13.h, wro_race_fsm.cpp, wro_v13_main.cpp]
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2026-05-10 src: archive v11 legacy firmware under src/esp32/legacy/
    The legacy_*.cpp files are v11 reference code (predates the v12-hybrid /
    v13 ESP32-S3 migration). They use v11 hardware pins and won't run on v13.
    Moving them into a legacy/ subfolder makes the active firmware tree
    unambiguous for compile and review.
    Arduino IDE only auto-includes sources directly inside the sketch folder,
    so legacy targets become non-buildable in-place. To resurrect one, copy
    the .cpp back into src/esp32/ temporarily (see legacy/README.md).
    - mkdir src/esp32/legacy/, git mv all legacy_*.cpp into it
    - Add src/esp32/legacy/README.md (target table + revival instructions)
    - src/esp32/esp32.ino: update target comment blo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
    [esp32.ino, legacy_eps323.cpp, legacy_test_motor_servo_drive.cpp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]
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2026-05-19 fix(esp32/fsm): harden E-Stop resume against RS_TURN drop and RS_INIT lockout
    Two latent bugs in RS_SAFE_STOP recovery:
    1. The ternary forced RS_RUN_OPEN whenever prevRaceState was RS_TURN. The
    RS_TURN enum is reserved (corner handling runs implicitly inside
    RS_RUN_OPEN/OBS), so it never triggered today — but if a future change
    ever set prevRaceState = RS_TURN during an Obstacle race, the operator
    would silently drop into Open mode after releasing E-Stop. Now respects
    the compile-time OBSTACLE_MODE flag.
    2. E-Stop pressed during RS_INIT/RS_WAIT_START left prevRaceState = RS_INIT,
    which failed the resume allow-list and stranded the robot in RS_SAFE_STOP
    until power cy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
    [wro_race_fsm.cpp]
2026-05-19 fix(esp32/sensors): warn on dual VL53L1X boot failure; name TOF_INVALID_MM
    If both Front and Side VL53L1X sensors fail to init at boot, both .ok flags
    silently go false and the corner FSM never sees a wall — the robot drives
    straight forever with no visible reason. Print a loud Serial WARN block
    during init when both fail, so the operator can check XSHUT wiring, I2C
    pull-ups, and the 2.8 V rail before wasting a race attempt.
    Also introduce TOF_INVALID_MM = 9999 in wro_hw_config_v13.h (alongside the
    existing TOF_MAX_VALID_MM) and replace the literal 9999 sentinels in:
    - vl53l1x_dual.h (4 sites in the driver itself)
    - wro_corner.cpp (frame validity check + lastTfMm init)
    - wro_behavio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
    [vl53l1x_dual.h, wro_behavior_open.cpp, wro_corner.cpp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]
2026-05-19 fix(esp32/obstacle+park+imu): blend cleanup, parking doc, drop redundant Wire.begin
    Three small hygiene fixes that don't change runtime behavior:
    - wro_behavior_obstacle.cpp: drop the dead (1.0f - blend) * 0.0f term in the
    pillar→heading-hold blend (algebraically identical to blend * hu; the
    compiler already folded it). Add a static_assert(PILLAR_BLEND_OUT_MS > 0)
    near the includes so a future zero in that config divisor is caught at
    compile time, not at runtime in the field.
    - wro_park.cpp: document what cam.extraTag carries (the magenta block's
    center-relative X in OpenMV image coords) and the sign convention for
    bayDir. The undocumented (cam.extraTag >= 0) ? +1 : -1 line w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
    [wro_behavior_obstacle.cpp, wro_imu.cpp, wro_park.cpp]
2026-05-19 fix(openmv+bench): guard UART3 init; replace String with C buffer in bench test
    - openmv_main.py: wrap UART(3, 115200, ...) construction in try/except. If
    UART3 is missing or busy (e.g., wrong port number on a non-H7-Plus board)
    the script previously hard-crashed silently with no packets reaching the
    ESP32 and no visible debug feedback. Now blinks the red LED fast forever
    so the failure is obvious on the field. Happy path unchanged.
    - bench_test_v13.cpp: replace the three Arduino String accumulators
    (camLast / inputBuf / uartBuf) with fixed-size char[] buffers, mirroring
    the production C-buffer pattern in wro_camera.cpp. String concatenation
    on a 50 Hz UART stream causes heap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
    [openmv_main.py]
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2026-05-19 models: add AS5600 encoder bracket + magnet adapter
    Parametric 3D-printable bracket (PETG) for mounting AS5600 magnetic
    encoders on rear wheels of the HSP 94182 chassis, plus a small
    centering adapter so the magnet stays concentric with the rotation axis.
    Designed to fix wheel-encoder shake that was corrupting odometry data
    under motor load.
    Three fabrication paths in one package:
    - AS5600_bracket.scad: parametric OpenSCAD source (ARM_REACH, ARM_RISE,
    PCB_HOLE_SPACING exposed as variables for measure-then-print workflow).
    L-bracket with triangulated gusset, vertical slots for chip-to-axle
    alignment, anchors to chassis side (not floor) for rigidity.
    - magnet_adapter.scad: small disc wi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
    [AS5600_bracket.scad, magnet_adapter.scad]
2026-05-20 models/AS5600_bracket: add stability truss (strut + gussets + buttresses)
    The original v1.0 bracket was a pure cantilever with a single gusset.
    Even with PETG it would still flex under motor torque, defeating the
    purpose of fixing the AS5600 shake. Converts the design into a proper
    triangulated truss so the cantilever bending load becomes axial
    strut tension/compression — about 50x more material-efficient.
    New stability features (all enabled by default, individually toggleable):
    - Diagonal strut from sensor wall back down to the riser base, in the
    same XZ plane as the arm. Single biggest rigidity win. Routed to
    avoid the M3 anchor holes and to not protrude behind the chassis face.
    - D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
    [AS5600_bracket.scad, AS5600_bracket.stl, magnet_adapter.stl]
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2026-05-29 fix(esp32/watchdog): drop duplicate WDT config (build-breaker), fix stale 500ms comments
    setup() declared esp_task_wdt_config_t wdt_cfg twice in one scope (a C++ redefinition that did not compile). Removed the early 500ms init block; the single arm-last reconfigure()+add(NULL) remains (Arduino-ESP32 v3.x auto-inits the TWDT). Fixed the loop() comment that said >500ms (actual WDT_TIMEOUT_MS=200) and clarified the blink-loop reset() is a no-op until the WDT is armed. Audit CRITICAL-0, #13, #15.
    [wro_v13_main.cpp]
2026-05-29 fix(esp32/fsm): correct inverted lap-count sign; brownout proxy covers reverse
    Lap count used g_yaw_total*globalDirection/360. With +yaw=CCW that is negative in BOTH race directions (CW: neg*+1; CCW: pos*-1), so ilaps stayed <=0 and g_lap_count never incremented -> the robot never reached FINISH (Open) or the parking trigger (Obstacle): a guaranteed failed run. Now counts fabsf(g_yaw_total) (direction-independent; lastIlaps monotonicity still rejects back-spin). Brownout proxy uses abs() so reverse (parking) stalls are caught. RS_TURN marked intentionally reserved. Audit #1 CRITICAL, #19, #20. BENCH: 3 laps each direction -> lap_count reaches 3.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
    [wro_race_fsm.cpp]
2026-05-29 fix(esp32/corner+sensors): honor pre-corner slowdown; reject stale ToF readings
    corner_active() returned true only for BRAKE/EXECUTE, so during SLOWDOWN/COMMIT the behavior module overwrote the reduced corner speed with full PWM and the robot reached the wall zone at full speed; it now owns control from the first slowdown tick. sens_tf_front_ok()/side_ok() had no staleness check, so a wedged VL53L1X (dataReady stuck false) held its last-good distance forever (phantom corner / masked wall); now gated on (millis()-lastRead)<TF_SILENT_MS, wiring in the previously-dead constant+accessor. Removed dead g_corner_exit_yaw. Audit #2, #3 HIGH, #18.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
    [wro_corner.cpp]
2026-05-29 fix(esp32/i2c+vision): add I2C bus timeouts; correct pillar pixel scale
    No I2C transaction had an explicit timeout, so one wedged bus could stack blocking reads past WDT_TIMEOUT_MS=200 and panic-reset mid-run before the ENC/IMU fail-limits could degrade gracefully; added Wire/Wire1 setTimeOut(10). Camera X is +-80 (cx-80 on a 160px frame), not +-160, so PILLAR_OFFSET_PX=60 was sized for a span that never existed (steers on a dead-ahead pillar, asymmetric avoidance); rescaled to 30 (RE-TUNE ON TRACK with PILLAR_KP). VL53L1X address remap is now verified (ACK at target addr) instead of trusting void setAddress(). Audit #5, #4 HIGH, #12.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
    [vl53l1x_dual.h, wro_config_v13.h]
2026-05-29 fix(esp32/imu+park): guard gyro NaN and stale yaw-rate; clamp park steering
    imu_update() had no finite check, so a single NaN gyro sample poisoned g_yaw/g_yaw_total permanently while g_imu_ok stayed true (no SAFE_STOP); now isfinite-guarded and counted toward IMU_FAIL_LIMIT, and g_yaw_rate is zeroed on any dropped/invalid sample so parking sees no-rotation rather than a frozen value. Park steering (CENTER + HEADING_KP*herr) is clamped in-module instead of relying only on writeSteeringUs(). begin_I2C() passes &Wire explicitly. Audit #7, #17, #11, #22.
    [wro_imu.cpp, wro_park.cpp]
2026-05-29 docs(openmv): fix pixel range (+-80 not +-160), checksum example, version label
    RedX/GreenX/ExtraTag are cx-80 on a 160px frame (+-80), not +-160 — corrected in the protocol doc, wro_camera.h and openmv_main.py, and clarified not-seen is dist==999 (not X==0). The worked-example checksum was wrong (XOR of the sample is 0F, not 7F). Bumped the ESP32 header UART v3 label to v3.1. Doc/comment only. Audit #4 doc, #14, #23.
    [openmv_main.py]
2026-06-05 feat(esp32): no-encoder run mode + v13 audit follow-ups
    Lets the v13 robot run while the AS5600 magnet is missing, plus the four
    follow-up findings from the post-audit code review.
    No-encoder mode (wro_config_v13.h: ENCODERS_PRESENT 0):
    - sensorsHealthy() drops the g_enc_ok gate (IMU-only) so the missing
    magnet can't trap the FSM in RS_INIT
    - parking reverse phases fall back to time (PARK_PHASE_A/C_MS) instead of
    encoder distance
    - brownout proxy disabled (no wheel-speed signal)
    - odo_init() still called for I2C bus bring-up
    Set ENCODERS_PRESENT back to 1 when the replacement magnet is fitted.
    Audit follow-ups:
    - A: explicit i2c_buses_init() (new wro_i2c_buses.h) so IMU + VL53L1X no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
    [wro_config_v13.h, wro_hw_config_v13.h, wro_park.cpp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]
2026-06-07 fix(esp32+openmv): harden failsafes from competition-critical review
    Code-review pass over the v13 firmware. Applies only the vetted
    competition-critical findings; by-design items were intentionally skipped.
    - park: cap PK_REV_B counter-steer with PARK_PHASE_B_MS so a non-converging
    heading can't reverse into a wall forever
    - park: abort PK_APPROACH after PARK_APPROACH_MAX_MS if the back wall is never
    detected (dead front ToF / lost marker) instead of creeping forward forever
    - imu: reject finite gyro spikes beyond ~500 dps full-scale (IMU_GYRO_MAX_RPS),
    not just NaN/Inf -- IMU is the sole reference in no-encoder mode
    - vl53l1x: only accept reads with range_status == RangeValid
    - race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
    [openmv_main.py, vl53l1x_dual.h, wro_config_v13.h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]
2026-06-10 fix(esp32): move I2C1 to GPIO3/4, wake VL53L1X XSHUT in I2C scanner
    - I2C1 (Wire1) rewired from GPIO11/12 to GPIO3/4; all driver headers and
    diag comments updated. GPIO3 is a strapping pin (JTAG sel) — noted in
    the pin map with GPIO13 as fallback if boot ever misbehaves.
    - diag_scan_i2c_v13: drive both VL53L1X XSHUT pins HIGH before scanning;
    with XSHUT on a GPIO the sensors sit in shutdown and never ACK, so a
    correctly wired board previously scanned as "missing".
    [diag_scan_i2c_v13.cpp, diag_test_encoders.cpp, diag_test_vl53l1x.cpp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]
2026-06-10 fix(esp32+openmv): control-law signs, camera deadlock, failsafes (full review)
    Control-law sign bugs (each race-losing on its own, never falsified on
    track — robot has been bench-only):
    - Heading-hold PID was positive feedback: +yaw=CCW but +µs=right, so
    CENTER+u ramped to full lock on any heading error. Negated into
    servo-space in open behavior, obstacle no-pillar blend, and parking
    PK_APPROACH. PK_REV_C keeps `+` (reversing inverts steering↔yaw).
    NEEDS the 2-min bench polarity check before first drive.
    - Red/green pillar pass sides were inverted vs the rulebook: red is now
    held LEFT of image center (vehicle passes on the pillar's right),
    green RIGHT. Far-pillar pre-positio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
    [openmv_main.py, wro_behavior_obstacle.cpp, wro_behavior_open.cpp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]
2026-06-10 feat(esp32): v13 servo-calibration target, motor/servo shim, bench µs servo
    - New target 7: diag_test_servo_calibrate_v13.cpp — interactive µs
    calibration for servo center and end-stops (replaces the archived v11
    version; falls back to local defines when compiled standalone).
    - New target 3 shim: target_test_motor_servo_drive.cpp includes the
    legacy drivetrain test from legacy/ so it builds again without copying.
    - Bench test: servo driven in microseconds with explicit attach range and
    50 Hz period, matching the main firmware (was degree-based write()).
    - Build-target tables (header, .ino, README) updated: 3 and 7 are
    buildable v13 targets now; arduino-esp32 requirement pinned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
    [diag_bench_test_v13.cpp, diag_test_servo_calibrate_v13.cpp, esp32.ino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]
2026-06-10 feat(models): 4mm magnet adapter rev, x2 print plate, assembly previews, OpenMV mount
    - magnet_adapter: pocket resized for the actual 4x2 mm diametric magnet
    (datasheet nominal was 6 mm), drop-in glue clearance 0.30; knurl teeth
    now straddle the disc OD (watertight union, no zero-width slivers);
    ghost magnet preview gated on $preview so it never bakes into the STL.
    - magnet_adapter_x2: two-up print plate. magnet_dummy: bench stand-in.
    - assembly.scad/stl + iso/side/top PNG previews of the full encoder stack.
    - models/OpenMV_H7_mount: camera mount for the H7 Plus.
    [assembly.scad, assembly.stl, magnet_adapter.scad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]
2026-06-10 feat(esp32): magnet installed — remove no-encoder fallback paths
    The replacement magnet is glued and the AS5600 air-gap verified, so every
    ENCODERS_PRESENT==0 branch we added on 2026-06-05 is dead code now.
    Removed:
    - ENCODERS_PRESENT macro itself (wro_config_v13.h section 0b gone).
    - Time-based parking phase-completion fallbacks (PARK_PHASE_A_MS,
    PARK_PHASE_C_MS): PK_REV_A / PK_REV_C are encoder-distance only again.
    - Guards around odo_update() in the main loop, around the AS5600 health
    check in setup(), around g_enc_ok in sensorsHealthy(), and around the
    brownout/stall proxy (back on — needs g_speed_cm_s).
    - "no-encoder mode" / "no-magnet mode" notes in wro_imu.cpp,
    wro_i2c_bu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
    [wro_config_v13.h, wro_imu.cpp, wro_park.cpp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]
2026-06-12 feat(esp32+espcam): camera fallbacks after OpenMV sensor-module damage
    OpenMV H7 Plus OV5640 module died during a reseat on 2026-06-12
    (5 days before competition). Two drop-in replacements, zero FSM changes:
    - Pixy2/2.1 binary backend (wro_camera_pixy2.cpp) on the same UART2
    pins; CAMERA_BACKEND switch in config §12 picks which backend
    compiles. Active backend is now PIXY2.
    - ESP32-CAM "fake OpenMV" sketch (src/espcam/) emits the same v3.1
    text frames as openmv_main.py — plan C if the Pixy falls through.
    - New diag target 12 (diag_test_camera.cpp): UART2 link check with
    plain-language verdict (NO BYTES / GARBAGE / BAD CHECKSUM / OK).
    - Setup guide docs/guides/WRO_Pixy2_Setup.md (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
    [WRO_Maintenance_Log.csv]
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2026-06-12 feat(esp32): encoder magnet-health + connection-stability diagnostics
    Target 8 (diag_test_encoders) now runs a 4-step sequence instead of a
    bare odometry readout:
    1. CONNECTION — I2C ACK on both buses
    2. MAGNET — AS5600 STATUS (MD/ML/MH) + AGC + magnitude, with
    plain-language gap advice (too weak / too strong / no magnet)
    3. STABILITY — 15 s read soak with error rate, worst burst and
    angle-jitter envelope; wiggle cables to expose loose crimps
    4. ODOMETRY — live raw/deg/cm + per-side I2C error counters
    Live keys: s = re-soak, m = magnet health, z = zero, h = help.
    as5600_dual_i2c.h grows the STATUS/AGC/MAGNITUDE register reads the
    diag target uses.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
    [diag_test_encoders.cpp]
2026-06-12 fix(esp32+openmv): matte-black-wall retunes, fixed camera exposure, real E-Stop
    From the 2026-06-11/12 run logs and bench sessions:
    - VL53L1X: Medium → Long distance mode (same 50 ms budget, 20 Hz).
    Medium collapsed to ~600 mm on the matte-black WRO walls; Long buys
    back range on dark targets.
    - Corner FSM: TURN_COMMIT_MM 350 → 420 — the black wall only returns
    stable frames from ~420 mm, waiting for 350 started EXECUTE at
    ~175 mm and tripped TURN_PANIC. TURN_BRAKE_MS 180 → 100 (old value
    ate ~14 cm at 0.8 m/s). OPEN_MAX_PWM 80 → 65 while front-ToF range
    on black walls stays short.
    - E-Stop: ESTOP_BYPASS_AUTOSTART path now reads the real button —
    the start button i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
    [openmv_main.py, vl53l1x_dual.h, wro_config_v13.h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]
2026-06-13 feat(models): Pixy2.1 bolt-through camera mount + setup-guide fix
    Adapt OpenMV_H7_mount into models/Pixy2_mount: bolt-through on Pixy2's
    3 official holes (3x M2.5/4-40), same chassis footprint + 15deg downtilt,
    lens height matched to OpenMV so PIXY_FOCAL_PIX barely shifts. Parametric
    .scad + exported STL + fit-check renders + README.
    Correct WRO_Pixy2_Setup.md: Pixy2 has 3x dia-3mm holes (not 4x M2.5),
    official coords + board dims per docs.pixycam.com.
    [pixy2_mount.scad, pixy2_mount.stl]
2026-06-13 feat(esp32): camera-assisted corner entry + 3-point saw turn (matte-black walls)
    The matte-black competition walls only return valid front-VL53L1X frames
    ~400-450 mm, too late to clear an 80° corner in one forward arc from the
    car's ~55 cm turn radius (2026-06-13 run: stalled ~27° → TURN_PANIC →
    CN_FAIL). Two new mechanisms, both kept distance+IMU-authoritative so the
    camera can never *fire* a turn (the v11 failure):
    - CORNER_CAMERA_SLOWDOWN: orange/blue mat line is an early SLOWDOWN-only
    trigger; COMMIT still requires the ToF wall.
    - CN_BACK 3-point "saw" turn: reverse-and-continue (counter-steered so yaw
    keeps rotating the same way) instead of aborting when the wall closes
    mid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
    [wro_build_target.h, wro_config_v13.h, wro_corner.cpp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]
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

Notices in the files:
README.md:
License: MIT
